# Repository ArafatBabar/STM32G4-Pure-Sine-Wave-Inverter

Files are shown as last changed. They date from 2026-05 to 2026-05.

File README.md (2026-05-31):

# STM32G4-Pure-Sine-Wave-Inverter
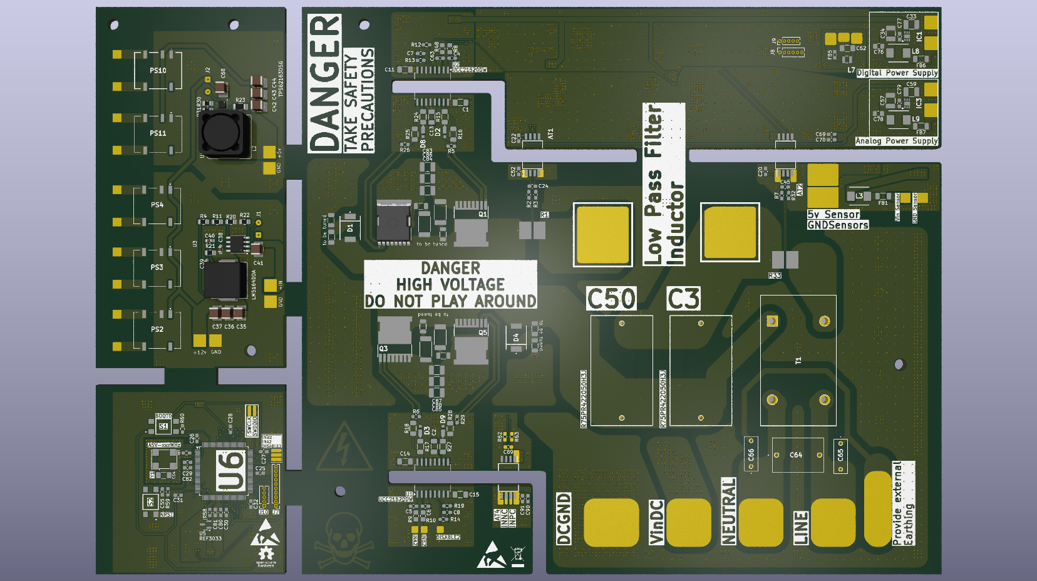
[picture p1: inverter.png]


A 1kW Two-Stage Pure Sine Wave Inverter based on the STM32G474 microcontroller.

The project converts a three-phase AC source into a regulated 400V DC link and then generates a low-distortion 230V RMS 50Hz pure sine wave output using SPWM-controlled full-bridge inverter topology.

## Specifications

| Parameter | Value |
|---|---|
| Output Power | 1kW Peak |
| Continuous Power | 800W |
| Output Voltage | 230V RMS |
| Output Frequency | 50Hz |
| DC Bus Voltage | 400V |
| Switching Frequency | 20kHz |
| Controller | STM32G474QETx |
| Modulation | Unipolar SPWM |
| Output Filter | LC Low Pass |
| Target THD | <3% |

## System Architecture

3 Phase AC
      │
      ▼
Rectifier
      │
      ▼
400V DC Link
      │
      ▼
Full Bridge Inverter
      │
      ▼
LC Filter
      │
      ▼
230V RMS 50Hz Output

## Features

- STM32G474-based control system
- 20kHz SPWM generation
- Isolated gate drivers
- Current sensing
- Voltage sensing
- LC output filtering
- High-voltage DC link architecture
- Modular PCB design
- Future-ready closed-loop control architecture

## Hardware Overview

### Power Stage
- Full bridge MOSFET inverter
- 400V DC bus
- LC output filter

### Controller Board
- STM32G474QETx
- ADC-based sensing
- PWM generation

### Gate Driver Board
- UCC21520 isolated gate driver

### Auxiliary Power Supply
- High-voltage DC/DC converter
- Isolated supplies

## Development Timeline

1. Topology selection
2. Simulation in PSIM
3. Schematic design
4. PCB design
5. Fabrication
6. Assembly
7. Firmware development
8. Hardware validation
9. Final testing

## Team

Project Team:

- Arafat Babar
- Vedant Acharya
- Krisha Pandya
- Ketan Pitroda
- Dev Bhavsar
- Yash Patel
- Raj Gediya
- Pritha Patel

Guides:

- Prof. Ketan Bhavsar
- Prof. Ankit Chauhan

## Design Notes and Lessons Learned

This project was developed as part of an academic power electronics course and represents a significant learning experience for the entire team.

While the system successfully demonstrates the design and implementation of a 1 kW STM32G4-based pure sine wave inverter, the current hardware revision is not without limitations. During development and review, several design decisions were identified that could be improved in future revisions.

Some areas identified for improvement include:

* PCB layout optimization for high-current switching paths.
* Improved isolation and creepage/clearance considerations in certain sections.
* Better placement of decoupling and filtering components.
* Additional protection circuitry and fault handling mechanisms.
* Improved EMI/EMC design practices.
* More comprehensive thermal analysis of power-stage components.
* Further validation of sensing and feedback circuitry under varying operating conditions.

This repository is intentionally published in its current state to document the complete engineering journey, including mistakes, trade-offs, design iterations, and lessons learned.

Engineering progress comes from testing assumptions, identifying weaknesses, and continuously improving designs. Future revisions will incorporate the insights gained from this prototype.

## Known Issues

The current revision contains several areas that will be revisited in future versions:

* Some PCB footprints and placements could be optimized for assembly and serviceability.
* High-current routing can be further improved to reduce loop inductance.
* Additional test points would simplify debugging and validation.
* Certain component selections were driven by availability and academic timelines rather than final production requirements.
* The control firmware is still under active development and tuning.
* The design has not yet undergone long-term reliability testing.

These observations are documented to encourage discussion and to help future iterations of the project.

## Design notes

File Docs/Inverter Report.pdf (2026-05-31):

POWER ELECTRONICS & DRIVES STUDIO | STU 601

## Design and Implementation of a Two-Stage Single-Phase Pure Sine Wave Inverter using STM32G4

This project is submitted as partial fulfillment of the requirement for the Power Electronics and Drives studio for Spring 2025-26.

Electrical and Electronics Engineering Navrachana University

April 2026

POWER ELECTRONICS & DRIVES STUDIO | STU601

### MEMBERS OF GROUP A

Sr. No. | Name | Enrollment ID | Signature
1 | Arafat Babar | 23000159 | __________
2 | Vedant Acharya | 23000229 | __________
3 | Krisha Pandya | 23000386 | __________
4 | Ketan Pitroda | 23000796 | __________
5 | Dev Bhavsar | 23001109 | __________
6 | Yash Patel | 23001111 | __________
7 | Raj Gediya | 23001115 | __________
8 | Pritha Patel | 23001118 | __________

### DECLARATION

We hereby declare that the report entitled “Two-Stage Single-Phase Pure Sine Wave Inverter using STM32G4” is a bonafide record of the work carried out by us in partial fulfillment of the requirements for the completion of the 6th semester Power Electronics and Drives Studio of Bachelor of Technology in Electrical and Electronics Engineering.

We further declare that this work has been carried out by us under the guidance of our supervisor and has not been submitted elsewhere for the completion of any other degree, diploma, or fellowship. All sources of information used in this report have been duly acknowledged.

We also affirm that this project is an original work and has been completed by us to the best of our knowledge and belief.

Signature of the Guide

Name of Guide: ____________________

Designation: ____________________

### ACKNOWLEDGEMENT

We would like to express our sincere gratitude to everyone who supported and guided us throughout the completion of our project titled “Design and Implementation of a Two-Stage Single-Phase Pure Sine Wave Inverter using STM32G4.”

We are highly thankful to Navrachana University for providing us with the opportunity, facilities, and resources required to successfully carry out this project work. The academic environment and technical support offered by the university greatly contributed to the successful completion of this project.

We would like to express our heartfelt gratitude to our respected project guides, Prof. Ketan Bhavsar and Prof. Ankit Chauhan, for their valuable guidance, continuous encouragement, and technical expertise throughout the project. Their insightful suggestions and constant motivation helped us overcome challenges and improve the quality of our work.

We would also like to extend our special thanks to Nicky Joshi and Jitendra Patel for their support, assistance, and helpful guidance during various stages of the project. Their encouragement and technical inputs played an important role in the successful implementation of the system.

This project involved extensive research, circuit design, hardware implementation, programming of the STM32G4 microcontroller, PWM generation, and inverter performance analysis. The teamwork, cooperation, and dedication shown by every group member were instrumental in achieving our objectives successfully.

Finally, we would like to thank all those who directly or indirectly contributed to the completion of this project. Without their support and encouragement, this work would not have been possible.

### ABSTRACT

This project presents the design and implementation of a Two-Stage Single-Phase Pure Sine Wave Inverter using the STM32G4 microcontroller for efficient DC to AC power conversion. The system is designed to generate a stable and low-distortion single-phase AC output suitable for domestic and industrial low-power applications. The inverter employs a two-stage conversion topology consisting of a rectification stage and an inverter stage to achieve improved voltage regulation, waveform quality, and operational reliability.

In the first stage, the AC input supply is converted into DC using an uncontrolled diode bridge rectifier. The rectified output is filtered using a capacitor bank to obtain a stable DC link voltage. In the second stage, a full-bridge inverter topology is implemented using MOSFET switches controlled by the STM32G4 microcontroller. The controller generates Sinusoidal Pulse Width Modulation (SPWM) signals to ensure accurate switching operation and to produce a sinusoidal output waveform with reduced harmonic distortion.

An LC low-pass filter is incorporated at the output stage to eliminate high-frequency switching harmonics and improve the quality of the generated sine wave. The proposed system is capable of delivering a 230 V RMS, 50 Hz single-phase AC output with efficient power conversion and reliable performance. The use of the STM32G4 microcontroller enables precise PWM generation, fast processing capability, flexible control implementation, and enhanced system stability.

The developed inverter system demonstrates advantages such as compact design, reduced Total Harmonic Distortion (THD), improved efficiency, electrical isolation, and scalability for future enhancements. This project highlights the practical implementation of modern power electronic conversion techniques and embedded control systems for pure sine wave inverter applications.

### TABLE OF CONTENTS

### LIST OF CHAPTERS

### LIST OF TABLES

### LIST OF FIGURES

Fig 5.6.1 72V/High Voltage to 12V Converter Schematic Diagram...41

Fig 5.9.1 Microcontroller and Control Interface Schematic Diagram.47

### LIST OF ABBREVIATIONS

Abbreviation | Full Form
AC | Alternating Current
ADC | Analog to Digital Converter
DC | Direct Current
EMI | Electromagnetic Interference
ESR | Equivalent Series Resistance
IC | Integrated Circuit
IoT | Internet of Things
LC Filter | Inductor-Capacitor Filter
MOSFET | Metal Oxide Semiconductor Field Effect Transistor
MCU | Microcontroller Unit
PCB | Printed Circuit Board
PI Controller | Proportional Integral Controller
PSIM | Power Simulation Software
PWM | Pulse Width Modulation
RC Circuit | Resistor Capacitor Circuit
RCD Clamp | Resistor Capacitor Diode Clamp
RMS | Root Mean Square
SPWM | Sinusoidal Pulse Width Modulation

THD | Total Harmonic Distortion
UPS | Uninterruptible Power Supply
VDC | Direct Current Voltage
VAC | Alternating Current Voltage
Hz | Hertz
kHz | Kilohertz
STM32G4 | STMicroelectronics 32-bit Microcontroller Series
GPIO | General Purpose Input Output
ADC | Analog to Digital Converter
ESR | Equivalent Series Resistance
H-Bridge | Full Bridge Inverter Configuration
CPU | Central Processing Unit
USB | Universal Serial Bus

### LIST OF APPENDIX

### CHAPTER 1

### INTRODUCTION

1.1 Background

The increasing demand for reliable and high-quality electrical power has led to the rapid development of power electronic conversion systems. In modern electrical and industrial applications, inverters play a vital role in converting Direct Current (DC) power into Alternating Current (AC) power suitable for domestic, commercial, and industrial loads [1]. Conventional square wave and modified sine wave inverters introduce significant harmonic distortion, reduced efficiency, and poor compatibility with sensitive electronic equipment. Therefore, Pure Sine Wave Inverters have become increasingly important due to their ability to provide clean, stable, and low-distortion AC output similar to utility power systems [2].

A two-stage inverter topology is widely preferred in modern power conversion systems because of its improved voltage regulation, flexibility, efficiency, and control capability [3]. In a two-stage architecture, the first stage performs AC to DC conversion and establishes a stable DC bus, while the second stage converts the DC voltage into a controlled sinusoidal AC output. This approach improves waveform quality, simplifies control implementation, and enhances system stability under varying load conditions [4].

The proposed project focuses on the design and implementation of a Two-Stage Single-Phase Pure Sine Wave Inverter using the STM32G4 microcontroller. The system utilizes a three-phase AC input supply which is fed through a variac for adjustable voltage control. In the first stage, a three-phase full-bridge rectifier converts the AC input into a high-voltage DC output of approximately 400 V DC. The rectified voltage is filtered using a capacitor bank to create a stable DC link for the inverter stage [1].

In the second stage, a full-bridge inverter topology operating at a switching frequency of 20 kHz is implemented using MOSFET switches. The inverter is controlled using Sinusoidal Pulse Width Modulation (SPWM) signals generated by the STM32G4 microcontroller [3]. The high-frequency PWM switching technique allows the inverter to produce an output waveform that closely resembles a pure sine wave. An LC low-pass filter is incorporated at the output stage to eliminate high-frequency harmonics and improve waveform quality [8].

The STM32G4 microcontroller is selected due to its advanced timer peripherals, high-speed processing capability, accurate PWM generation, and efficient real-time control features [5]. The controller also performs voltage and current sensing, PI-based control implementation, fault protection, and system monitoring to ensure safe and reliable operation.

The developed inverter system is designed to generate a stable 230 V, 50 Hz single-phase AC output, making it suitable for residential backup systems, laboratory applications, renewable energy systems, and low-power industrial loads. The project demonstrates the practical implementation of modern embedded control systems and power electronics techniques for efficient energy conversion [2], [4].

1.2 Project Objective

The primary objective of this project is to design and implement a Two-Stage Single-Phase Pure Sine Wave Inverter using the STM32G4 microcontroller capable of producing a stable and low-distortion AC output from a DC source.

The specific objectives of the project are as follows:

1. To design a two-stage power conversion system consisting of a rectification stage and an inverter stage.
2. To convert a three-phase AC supply into a stable high-voltage DC bus using a three-phase full-bridge rectifier and capacitor filtering network [1].
3. To generate a pure sinusoidal AC output of 230 V RMS at 50 Hz using a full-bridge inverter topology.
4. To implement Sinusoidal Pulse Width Modulation (SPWM) techniques using the STM32G4 microcontroller for accurate switching control of MOSFET devices [3], [5].
5. To reduce harmonic distortion in the output waveform using an LC low-pass filter [8].
6. To implement current sensing, voltage sensing, protection mechanisms, and PI control algorithms for improved system reliability and stability.
7. To achieve efficient power conversion with reduced switching losses and improved waveform quality [4].

8. To develop a compact, modular, and scalable inverter system suitable for practical applications and future enhancements.

1.3 Project Scope

The scope of this project includes the complete design, development, testing, and implementation of a two-stage single-phase pure sine wave inverter system using embedded control techniques and power electronic converters.

The project covers the following areas:

1. Design and implementation of the power stage consisting of a three-phase rectifier and full-bridge inverter topology [1].
2. Development of a stable 400 V DC bus using rectification and capacitor filtering techniques.
3. Generation of high-frequency SPWM signals using the STM32G4 microcontroller [5].
4. Design of gate driver circuits for MOSFET switching applications.
5. Implementation of an LC output filter for harmonic reduction and waveform smoothing [8].
6. Integration of voltage and current sensing circuits for feedback and protection.
7. Implementation of PI control algorithms for output regulation and system stability.
8. Testing and analysis of inverter performance under different operating conditions and load variations.
9. Measurement and evaluation of output voltage quality, switching performance, efficiency, and harmonic distortion.

The proposed inverter system can be further extended for applications such as renewable energy integration, solar inverter systems, UPS systems, battery energy storage systems, and industrial motor drive applications [6]. Future improvements may include closed-loop digital control, advanced modulation techniques, higher power ratings, IoT-based monitoring, and improved efficiency optimization methods.

### CHAPTER 2

### LITERATURE REVIEW

2.1 Pure Sine Wave Inverter

An inverter is a power electronic device used to convert Direct Current (DC) into Alternating Current (AC). Inverters are widely used in backup power systems, renewable energy systems, industrial drives, and domestic applications. According to Mohan et al. [1], modern inverter systems mainly focus on improving efficiency, reducing switching losses, and minimizing harmonic distortion in the output waveform.

There are mainly three types of inverter output waveforms: square wave, modified sine wave, and pure sine wave. Among these, pure sine wave inverters provide the best output quality because the generated waveform closely matches the utility AC supply [2]. Pure sine wave inverters are preferred for sensitive electronic devices, medical equipment, communication systems, and industrial loads due to their low Total Harmonic Distortion (THD) and stable operation.

The proposed project implements a pure sine wave inverter using a two-stage conversion system. The first stage converts AC input into DC using a rectifier circuit, while the second stage converts the DC link voltage into sinusoidal AC output using SPWM switching techniques.

2.2 Two-Stage Inverter Topology

The two-stage inverter topology is widely used in modern power conversion systems because of its improved flexibility, voltage regulation capability, and waveform quality [4]. In this topology, the first stage consists of an AC-DC converter or rectifier that generates a stable DC bus voltage. The second stage consists of a DC-AC inverter that produces the required AC output waveform.

In the proposed system, a three-phase full-bridge rectifier is used to convert the three-phase AC supply into approximately 400 V DC. A capacitor bank is connected across the DC link to reduce voltage ripple and maintain a stable DC bus voltage. The inverter stage uses a full-bridge MOSFET configuration operating at high switching frequency to generate AC output voltage.

The two-stage structure provides better isolation between rectification and inversion processes, improves output stability, and allows independent control of both stages. This topology is commonly used in UPS systems, renewable energy systems, and high-performance inverter applications [1], [4].

2.3 Sinusoidal Pulse Width Modulation (SPWM)

Pulse Width Modulation (PWM) is one of the most important switching techniques used in inverter systems. PWM techniques are used to control switching devices and generate output voltages with reduced harmonic distortion [3]. Among different PWM techniques, Sinusoidal Pulse Width Modulation (SPWM) is widely used because of its simple implementation and high-quality output waveform generation.

Holmes and Lipo [3] explained that SPWM is generated by comparing a high-frequency triangular carrier signal with a sinusoidal reference signal. The comparison produces PWM pulses that control the switching of MOSFETs in the inverter circuit. By varying the modulation index and switching frequency, the output voltage magnitude and waveform quality can be controlled.

SPWM significantly reduces lower-order harmonics and improves inverter efficiency. High-frequency switching also reduces the size of output filters required for harmonic reduction [8]. In this project, the STM32G4 microcontroller generates 20 kHz SPWM signals to control the inverter switching operation.

2.4 STM32G4 Microcontroller

Microcontrollers play an important role in modern inverter systems due to their ability to provide accurate switching control, sensing, protection, and feedback implementation. The STM32G4 series microcontroller developed by STMicroelectronics [5] is specifically designed for power electronic and motor control applications.

The STM32G4 controller provides advanced timer peripherals, high-speed Analog-to-Digital Converters (ADC), PWM generation units, dead-time insertion capability, and fault handling mechanisms. These features make the controller highly suitable for inverter applications requiring high-frequency switching and real-time control.

In the proposed project, the STM32G4 microcontroller is used for SPWM pulse generation, current and voltage sensing, PI control implementation, and protection handling. The controller ensures precise switching operation and stable output waveform generation.

2.5 MOSFET Switching Devices

Power semiconductor devices are the key components in inverter systems. MOSFETs are widely used in high-frequency inverter applications because of their fast switching speed, low switching losses, and simple gate drive requirements [2].

According to Ahmed [9], MOSFET-based inverter systems provide improved switching performance and higher efficiency in medium-power applications. MOSFETs are voltage-controlled devices and require comparatively lower gate drive power than conventional bipolar transistors.

In the proposed project, MOSFETs are used in a full-bridge inverter configuration for high-frequency switching operation. The switching signals generated by the STM32G4 controller control the MOSFET operation to generate SPWM output pulses.

2.6 LC Output Filter

The output waveform of an inverter contains high-frequency switching harmonics generated due to PWM operation. Therefore, filters are required to reduce harmonic content and improve waveform quality. LC low-pass filters are commonly used in pure sine wave inverter systems because of their ability to attenuate high-frequency harmonics while allowing the fundamental frequency component to pass [8].

Ang and Oliva [10] explained that proper filter design is important for achieving stable output voltage and minimizing distortion. The inductance and capacitance values must be selected carefully based on switching frequency, load conditions, and output voltage requirements.

In this project, an LC filter is connected at the inverter output stage to smooth the SPWM waveform and generate a clean 230 V, 50 Hz sinusoidal AC output.

2.7 Control and Protection System

Modern inverter systems require efficient control and protection mechanisms to ensure safe and reliable operation. Feedback control techniques such as PI controllers are widely used for maintaining stable output voltage under varying load conditions [6].

Krishnan [6] explained that voltage sensing and current sensing circuits are necessary for monitoring system performance and implementing closed-loop control. Protection systems are also required to prevent damage caused by overcurrent, short circuits, overheating, and abnormal operating conditions.

The proposed inverter system incorporates voltage sensing, current sensing, PI control algorithms, and fault handling techniques using the STM32G4 microcontroller. These features improve system stability, reliability, and operational safety.

2.8 Summary of Literature Review

Based on the literature survey, it is observed that modern pure sine wave inverter systems require efficient PWM techniques, high-frequency switching devices, advanced digital controllers, and effective filtering methods for achieving high-quality AC power conversion. Most researchers focused on improving inverter efficiency, reducing harmonic distortion, and implementing reliable embedded control systems.

The concepts studied from the reviewed literature were used in the development of the proposed project, which implements a two-stage pure sine wave inverter using a three-phase rectifier, STM32G4-based SPWM control, MOSFET switching, and LC filtering techniques.

### CHAPTER 3

### SYSTEM DESIGN APPROACH

3.1 Design Objective

The primary objective of the proposed system is to design and implement a Two-Stage Single-Phase Pure Sine Wave Inverter using the STM32G4 microcontroller capable of generating a stable and low-distortion AC output suitable for practical electrical applications. The system is designed to convert a three-phase AC input into a regulated DC voltage and further convert the DC voltage into a single-phase sinusoidal AC output using high-frequency switching techniques [1], [4].

The design aims to achieve efficient power conversion, reduced harmonic distortion, stable voltage regulation, and reliable switching operation. Another major objective is to implement Sinusoidal Pulse Width Modulation (SPWM) using the STM32G4 microcontroller for accurate control of MOSFET switching devices [3], [5]. The proposed system also focuses on implementing voltage sensing, current sensing, output filtering, and protection mechanisms to improve overall system stability and reliability [4], [6].

The inverter is designed to provide a 230 V RMS, 50 Hz pure sine wave output with improved waveform quality and reduced Total Harmonic Distortion (THD) [1], [2], [8].

3.2 Selection of Two-Stage Topology

The two-stage inverter topology was selected because of its improved flexibility, better voltage regulation capability, modular structure, and enhanced waveform quality compared to conventional single-stage inverter systems [4]. In a two-stage architecture, the power conversion process is divided into two separate stages: the rectification stage and the inversion stage.

In the first stage, a three-phase full-bridge rectifier converts the AC input supply into a high-voltage DC output. The rectified voltage is filtered using a capacitor bank to create a stable DC bus voltage. In the second stage, the DC voltage is converted into single-phase AC output using a full-bridge inverter operating with high-frequency SPWM switching [1], [3].

The two-stage topology provides several advantages such as improved output voltage stability, better harmonic reduction capability, independent control of rectifier and inverter stages, easier implementation of digital control techniques, improved scalability and modularity, and better suitability for high-frequency switching applications [4], [6]. Due to these advantages, the two-stage topology is widely used in UPS systems, renewable energy systems, and modern pure sine wave inverter applications [1], [2].

3.3 Block Diagram and System Flow

The overall system consists of three major sections: the power stage, inverter stage, and control stage. The system begins with a three-phase AC supply connected through a variac for adjustable input voltage control. The AC input is fed to a three-phase full-bridge rectifier which converts the AC voltage into approximately 400 V DC.

The rectified DC output is filtered using a capacitor bank to reduce voltage ripple and establish a stable DC link voltage. This DC bus is then supplied to the inverter stage consisting of a full-bridge MOSFET configuration operating with SPWM switching at 20 kHz.

The STM32G4 microcontroller generates SPWM pulses required for MOSFET switching control. The inverter output is passed through an LC low-pass filter to eliminate switching harmonics and generate a clean sinusoidal AC waveform. Voltage sensing and current sensing circuits continuously monitor the system parameters and provide feedback to the controller for stable operation and protection handling.

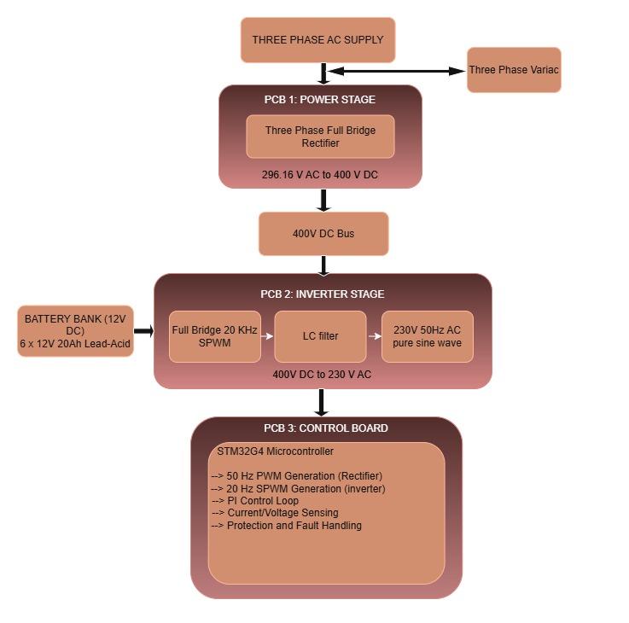
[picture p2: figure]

Fig 3.3.1 System Flow Chart
3.4 DC Link Design Concept

The DC link stage plays an important role in maintaining stable inverter operation and reducing voltage ripple between the rectifier and inverter stages. The DC link consists of a capacitor bank connected across the rectifier output to store energy and smooth the pulsating DC voltage generated by the rectifier [1], [4].

The capacitor bank helps in reducing ripple voltage, stabilizing DC bus voltage, improving inverter performance, providing temporary energy storage during switching operation, and reducing voltage fluctuations caused by load variations. Proper DC link design is essential for maintaining stable inverter operation and improving overall power conversion efficiency [2], [6].

The DC bus voltage for the proposed system is designed around 400 V DC. Proper capacitor selection is important because insufficient capacitance may increase ripple voltage and affect inverter output quality. High-voltage electrolytic capacitors with suitable ripple current ratings are used to ensure stable operation [1], [4].

The DC link design also improves transient response and ensures continuous power delivery to the inverter stage during high-frequency switching operation [3], [8].

3.5 Switching Strategy Selection (SPWM)

Sinusoidal Pulse Width Modulation (SPWM) was selected as the switching strategy for the proposed inverter system because of its simplicity, effectiveness, and ability to generate high-quality sinusoidal output waveforms with reduced harmonic distortion [3].

In SPWM, a high-frequency triangular carrier signal is compared with a low-frequency sinusoidal reference signal. The comparison generates PWM pulses that control the switching operation of the MOSFETs in the full-bridge inverter circuit. By varying the modulation index and switching frequency, the output voltage magnitude and waveform quality can be controlled [3], [8].

The major advantages of SPWM include reduced Total Harmonic Distortion (THD), better output voltage control, improved waveform quality, reduced filter size requirements, higher inverter efficiency, and simple implementation using digital controllers [2], [3].

The STM32G4 microcontroller generates 20 kHz SPWM signals with proper dead-time insertion to avoid shoot-through conditions in the inverter switches. The modulation index and switching frequency are selected carefully to achieve stable output voltage and efficient switching performance [5], [8].

3.6 Output Filtering Approach

The inverter output produced by SPWM switching contains high-frequency harmonics due to rapid switching operation of the MOSFETs. Therefore, an output filter is required to eliminate switching harmonics and obtain a smooth sinusoidal waveform [3], [8].

An LC low-pass filter is used in the proposed system because of its effective harmonic attenuation capability and simple design structure. The inductor opposes sudden current changes while the capacitor smooths voltage fluctuations, resulting in a cleaner output waveform [8], [10].

The LC filter is designed based on switching frequency, output frequency, load conditions, harmonic attenuation requirements, and voltage and current ratings.

Proper filter parameter selection is important for maintaining waveform quality and reducing Total Harmonic Distortion (THD) [3], [10].

The filter significantly reduces high-frequency switching components and improves the quality of the generated 230 V, 50 Hz AC output waveform [2], [8].

3.7 Design Specifications

The major design specifications of the proposed inverter system are listed below:

Table No 3.7.1 Key Design Parameters

Parameter | Value
Input Supply | Three-Phase AC Supply
DC Bus Voltage | Approximately 400 V DC
Output Voltage | 230V RMS
Output Frequency | 50 Hz
Inverter Type | Full-Bridge Single-Phase Inverter
Switching Technique | SPWM
Switching Frequency | 20 kHz
Controller | STM32G4 Microcontroller
Output Filter | LC Low-Pass Filter
Switching Devices | MOSFETs
Protection Features | Overcurrent, Overvoltage, Fault Handling
Output Waveform | Pure Sine Wave

3.8 Design Methodology Overview

The design methodology of the proposed inverter system follows a systematic approach involving circuit design, controller implementation, simulation, hardware development, testing, and performance evaluation [1], [4].

Initially, the overall system architecture and inverter topology were selected based on output requirements and power conversion efficiency. The rectifier stage and DC link section were designed to generate a stable high-voltage DC bus. The inverter stage was then designed using a full-bridge MOSFET configuration for high-frequency switching operation [1], [2].

The STM32G4 microcontroller was programmed to generate SPWM signals for inverter control. Voltage and current sensing circuits were integrated for monitoring and protection purposes. The LC filter parameters were selected to minimize harmonic distortion and improve waveform quality [3], [5], [8].

After hardware implementation, the system performance was tested under different operating conditions and load variations. Output voltage, waveform quality, switching performance, and inverter stability were analyzed to verify proper system operation [4], [6].

The proposed methodology provides a modular and scalable inverter design suitable for future improvements and practical power electronic applications [2], [4].

### CHAPTER 4

### PSIM SIMULATION

4.1 Introduction to Simulation

To validate the proposed system design before hardware implementation, simulations were carried out using PSIM software. Simulation helps in analyzing system behavior, verifying circuit operation, and evaluating output waveform quality under ideal conditions.

The simulation was performed in two stages. First, a single-phase inverter was simulated to understand SPWM-based DC-to-AC conversion. Then, the complete system including the three-phase rectifier, DC link, inverter, and LC filter was simulated to analyze overall performance.

4.2 SPWM Controlled Inverter Simulation

4.2.1 Circuit Description

The simulated circuit represents a single-phase full-bridge inverter using MOSFET switches. A DC input of approximately 400V is applied to the inverter.

SPWM is used as the switching technique, where a sinusoidal reference signal (50 Hz) is compared with a high-frequency triangular carrier signal (20 kHz). The resulting PWM signals control the switching of the MOSFETs in the H-bridge configuration.

The MOSFETs operate in diagonal pairs to produce alternating polarity across the load, resulting in a PWM-based AC waveform.

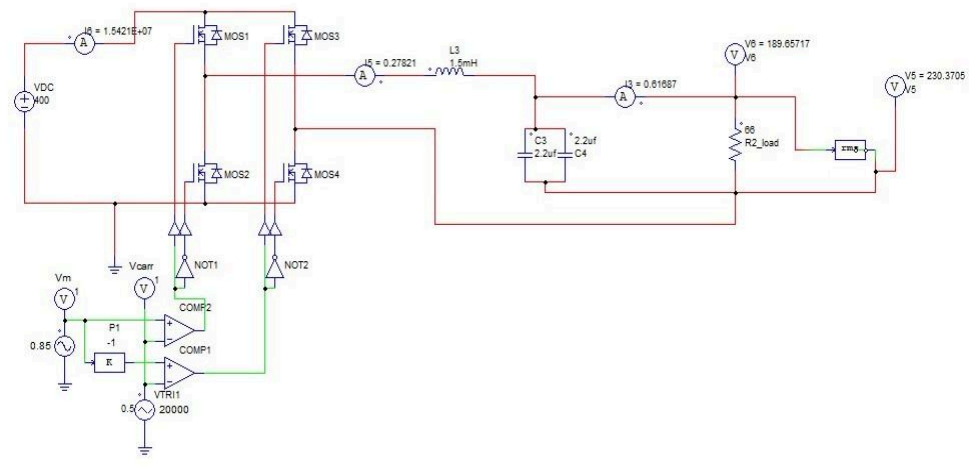
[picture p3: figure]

Fig 4.2.1 Inverter Simulation Circuit

4.2.2 Output Filtering

The output of the inverter consists of high-frequency PWM pulses, which contain harmonic components. To obtain a smooth sinusoidal waveform, an LC low-pass filter is used.

The inductor reduces rapid changes in current, while the capacitor smooths voltage variations. This combination effectively removes high-frequency components and retains the fundamental frequency.

4.3 Complete System Simulation (Rectifier + Inverter)

4.3.1 Rectifier Stage

The first stage of the simulation consists of a three-phase uncontrolled diode bridge rectifier. It converts the three-phase AC input into pulsating DC.

A capacitor bank is connected at the output of the rectifier to smooth the pulsating DC and form a DC link. This DC link provides a stable input voltage to the inverter stage.

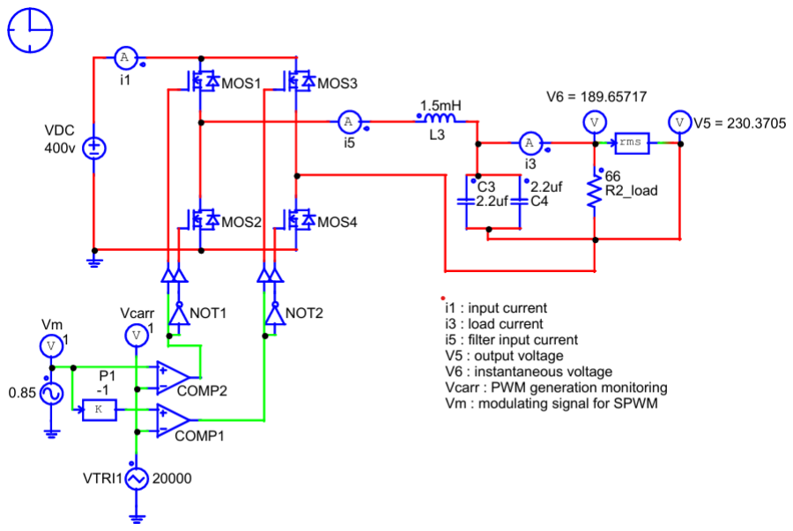
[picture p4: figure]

Fig 4.3.1 Rectifier Simulation Circuit

4.3.2 Inverter Stage

The DC link voltage is fed into the full-bridge inverter. The inverter uses SPWM signals to generate a high-frequency PWM waveform, which approximates a sinusoidal output.

The switching frequency is maintained at 20 kHz to ensure effective filtering and reduced harmonic distortion.

4.3.3 Output Filtering and Load

An LC filter is connected at the output of the inverter to remove high-frequency switching harmonics. The filtered output is applied to a resistive load.

The output waveform obtained after filtering closely resembles a sinusoidal waveform with reduced distortion.

4.4 Simulation Results and Analysis

4.4.1 Load Current

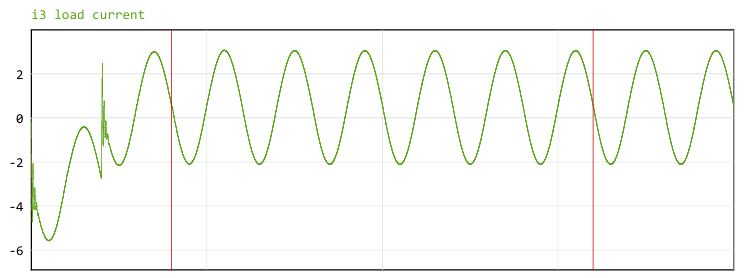
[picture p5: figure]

Fig 4.4.1 Load Current Waveform

The load current waveform shows a smooth sinusoidal pattern after filtering. This indicates that the LC filter effectively removes high-frequency components and allows only the fundamental frequency to pass.

4.4.2 Filter Input Current

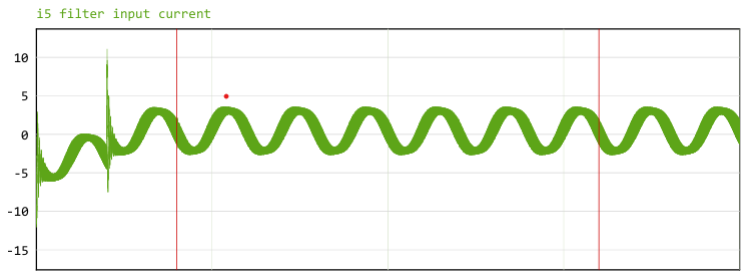
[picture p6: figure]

Fig 4.4.2 Filter Input Current Waveform

The current entering the filter contains high-frequency components due to switching action in the inverter. This waveform appears more distorted compared to the load current, confirming that the filter is actively removing unwanted harmonics.

4.4.3 Output Voltage

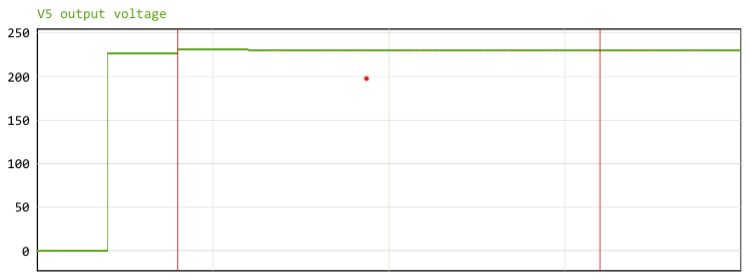
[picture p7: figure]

Fig 4.4.3 Output Voltage Waveform

The output voltage waveform after the LC filter is observed to be a stable sinusoidal waveform with an RMS value close to 230V. This confirms that the inverter is capable of producing the required output voltage.

4.4.4 Instantaneous Voltage

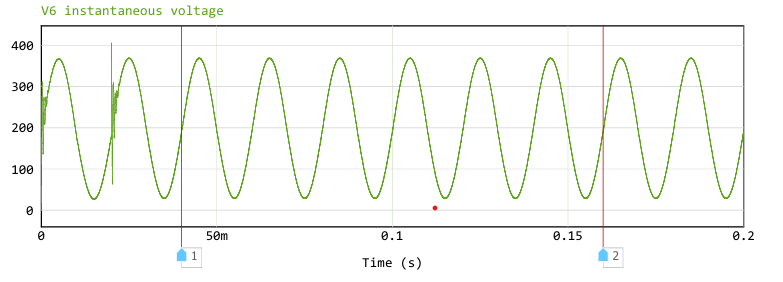
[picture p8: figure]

Fig 4.4.4 Instantaneous Voltage Waveform

The instantaneous voltage waveform shows the variation of voltage over time before filtering. It contains high-frequency switching components along with the fundamental frequency. After filtering, these high-frequency components are removed, resulting in a clean sinusoidal waveform.

4.5 Summary of Simulation

The simulation results confirm the proper operation of the two-stage inverter system. The rectifier successfully converts AC input into DC, and the inverter generates an AC output using SPWM control. The LC filter effectively reduces harmonic distortion and produces a clean sinusoidal waveform.

The simulation validates the design approach and provides confidence for proceeding to hardware implementation.

### CHAPTER 5

### HARDWARE IMPLEMENTATION

5.1 Introduction

After validating the system through simulation, the proposed two-stage inverter system was implemented in hardware. The implementation involves the design and integration of multiple subsystems, including the rectifier stage, DC link, inverter stage, gate driver circuits, auxiliary power supplies, sensing circuits, filtering stages, and control unit.

The hardware is designed using a modular approach, where power and control circuits are separated to improve safety, reduce noise interference, and simplify debugging. Proper consideration is given to isolation, thermal performance, and PCB layout to ensure reliable operation at high power levels.
5.2 Rectifier Circuit Design

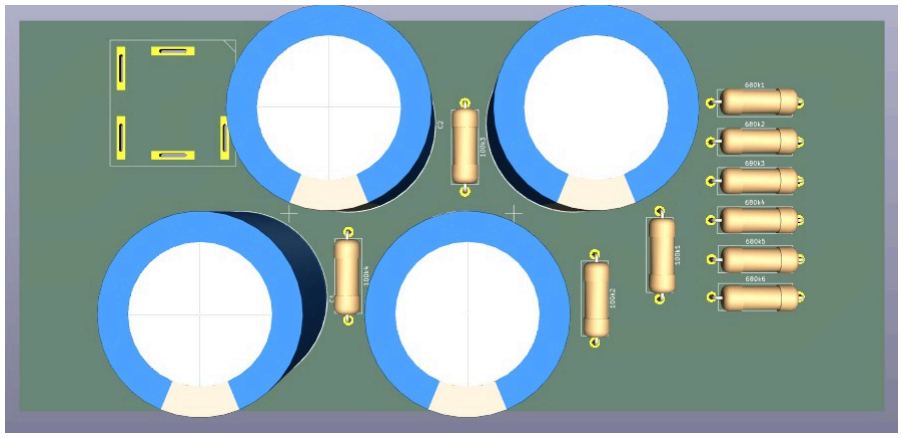
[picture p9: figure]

Fig 5.2.1 Rectifier PCB -1

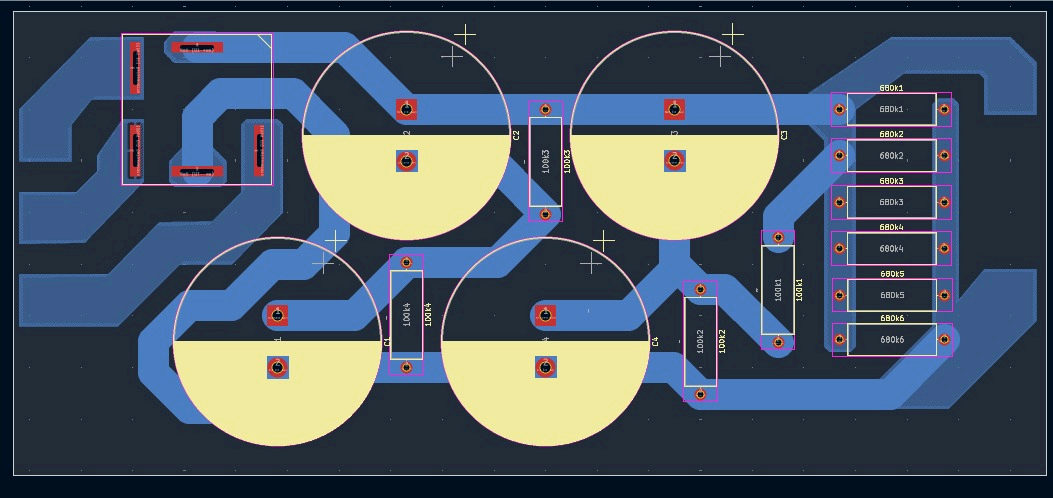
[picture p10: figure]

Fig 5.2.2 Rectifier PCB -2

Description:

The rectifier stage consists of a three-phase uncontrolled diode bridge, which converts the AC input supply into pulsating DC. The bridge is formed using six power diodes arranged in a full-wave configuration, where each phase contributes to the output during different intervals of the AC cycle.

Working Principle:

During operation, at any instant, two diodes conduct, one from the positive group and one from the negative group, allowing current to flow from the highest positive phase to the most negative phase. This results in a pulsating DC output with reduced ripple compared to single-phase rectification.

Key Components:

1. Power Diodes (D1–D6): Handle high voltage and current
2. Input Terminals: Three-phase AC supply
3. Output Terminals: DC output to DC link

Importance in System:

This stage provides the required DC voltage for the inverter. Its simplicity, reliability, and ruggedness make it suitable for high-power applications.

5.3 DC Link Design

Description:

The DC link connects the rectifier stage to the inverter and acts as an intermediate energy storage element. It consists of a capacitor bank designed to smooth the pulsating DC output from the rectifier.

Working Principle:

The capacitors charge during voltage peaks and discharge during voltage dips, thereby reducing ripple and maintaining a nearly constant DC voltage. This stabilized voltage is critical for proper inverter operation.

Design Considerations:

1. High voltage rating (≈400V)
2. High ripple current handling
3. Low Equivalent Series Resistance (ESR)
4. Proper spacing and PCB layout

Importance in System:

A stable DC link ensures consistent inverter performance, reduces stress on switching devices, and improves output waveform quality.

5.4 Inverter Circuit Design

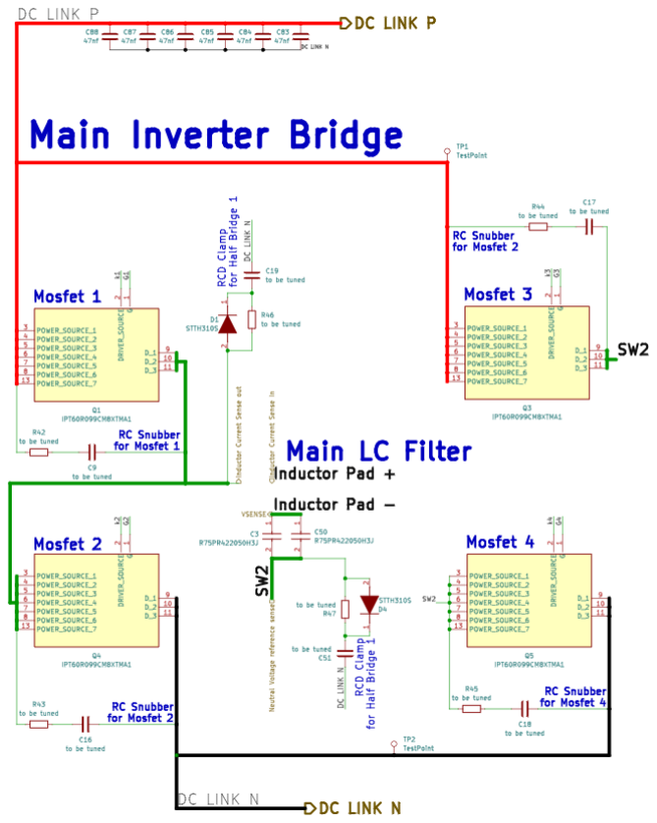
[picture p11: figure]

Fig 5.4.1 Inverter Schematic Diagram

Description:

The inverter stage converts DC into AC using a full-bridge configuration consisting of four N-channel MOSFETs. The MOSFETs are controlled using SPWM signals generated by the microcontroller.

Working Principle:

The MOSFETs operate in diagonal pairs (Q1–Q4 and Q2–Q3). By switching these pairs alternately, the polarity of the voltage across the load is reversed, producing an AC waveform. The switching is performed at a high frequency (20 kHz) to enable efficient filtering.

Protection Features:

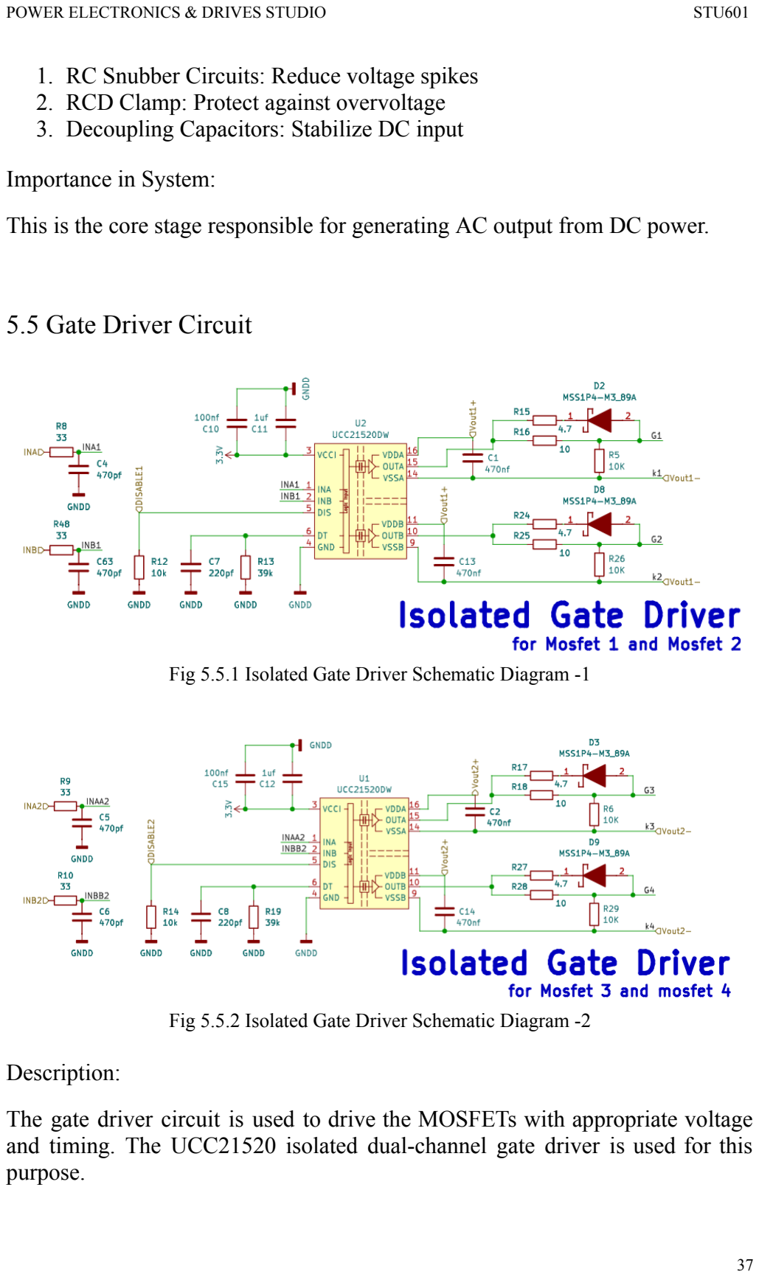
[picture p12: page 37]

1. RC Snubber Circuits: Reduce voltage spikes
2. RCD Clamp: Protect against overvoltage
3. Decoupling Capacitors: Stabilize DC input

Importance in System:

This is the core stage responsible for generating AC output from DC power.

5.5 Gate Driver Circuit

Fig 5.5.1 Isolated Gate Driver Schematic Diagram -1

Fig 5.5.2 Isolated Gate Driver Schematic Diagram -2

Description:

The gate driver circuit is used to drive the MOSFETs with appropriate voltage and timing. The UCC21520 isolated dual-channel gate driver is used for this purpose.

Working Principle:

The driver receives PWM signals from the microcontroller and amplifies them to drive the MOSFET gates. It also provides electrical isolation between the control and power stages.

Key Features:

1. Reinforced isolation
2. Dead-time control to prevent shoot-through
3. High switching speed
4. Separate isolated supplies

Importance in System:

Ensures safe, efficient, and synchronized switching of MOSFETs.

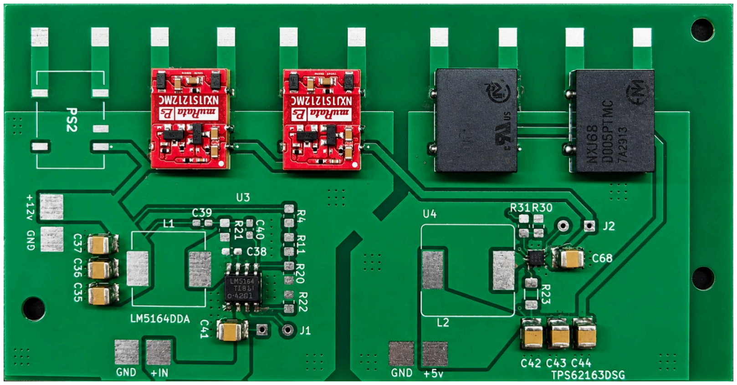
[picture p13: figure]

Fig 5.5.3 Isolated Gate Driver PCB

5.6 Auxiliary Power Supply Design

5.6.1 72V/High Voltage to 12V Converter

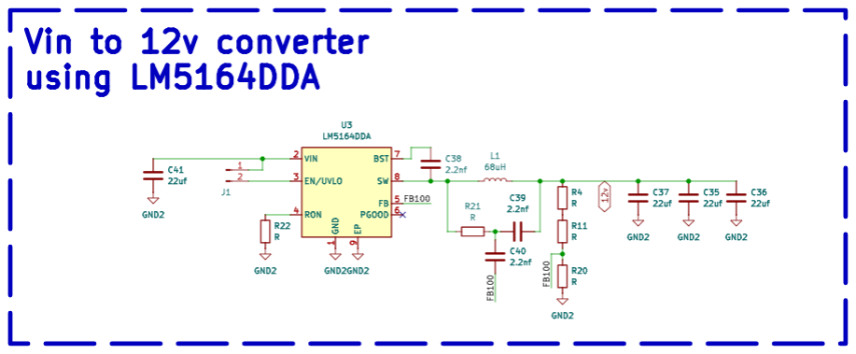
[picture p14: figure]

Fig 5.6.1 72V/High Voltage to 12V Converter Schematic Diagram

This converter steps down the high input voltage to 12V, which is used to power gate drivers and intermediate circuits.

5.6.2 12V to 5V Converter

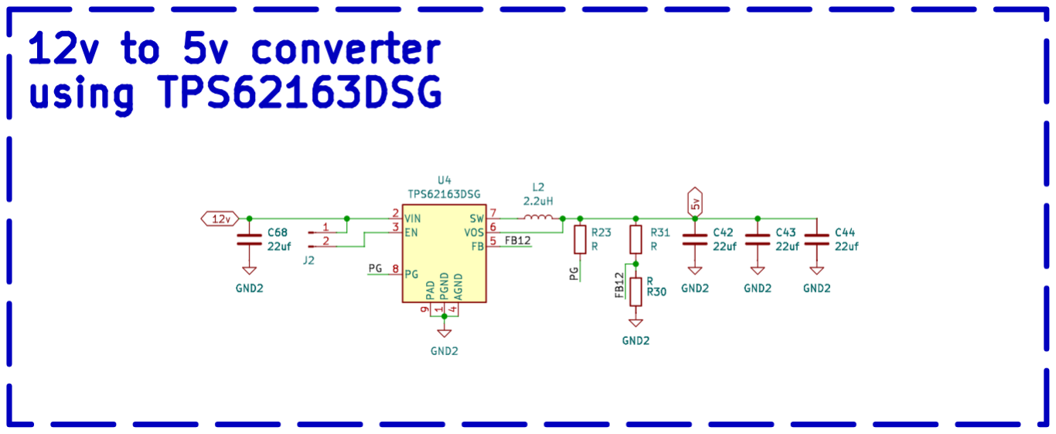
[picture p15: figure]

Fig 5.6.2 12V to 5V Converter Schematic Diagram The 12V to 5V buck converter provides a stable 5V supply for low-voltage components such as sensors and auxiliary circuits.

5.6.3 Isolated Power Supply

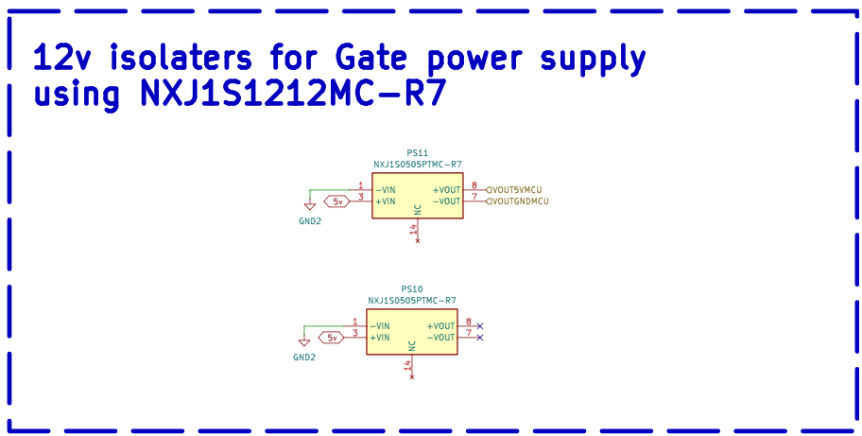
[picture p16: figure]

Fig 5.6.3 Isolated Power Supply Schematic Diagram -1

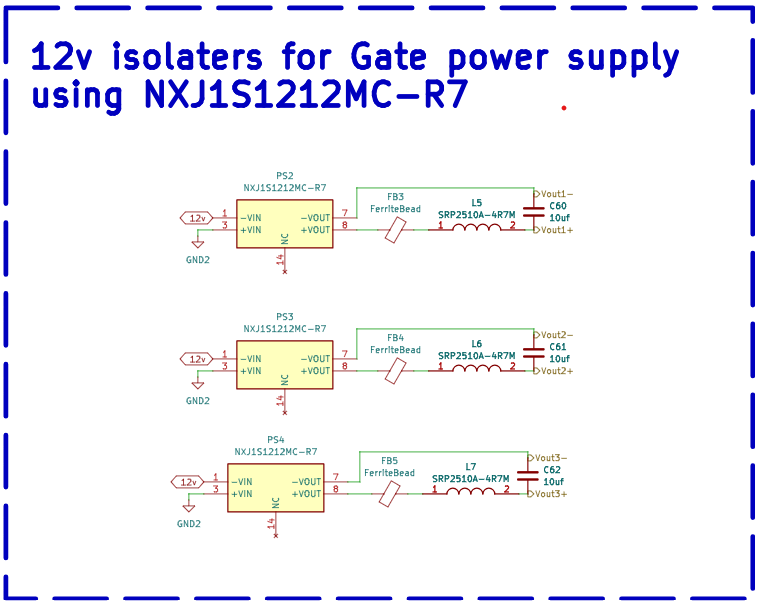
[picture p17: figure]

Fig 5.6.4 Isolated Power Supply Schematic Diagram -2 Isolated DC-DC converters are used to provide an isolated ±12V supply for gate drivers. This ensures safe operation and prevents noise coupling between control and power circuits.

5.7 Sensing and Measurement Circuits

5.7.1 Output Current Measurement

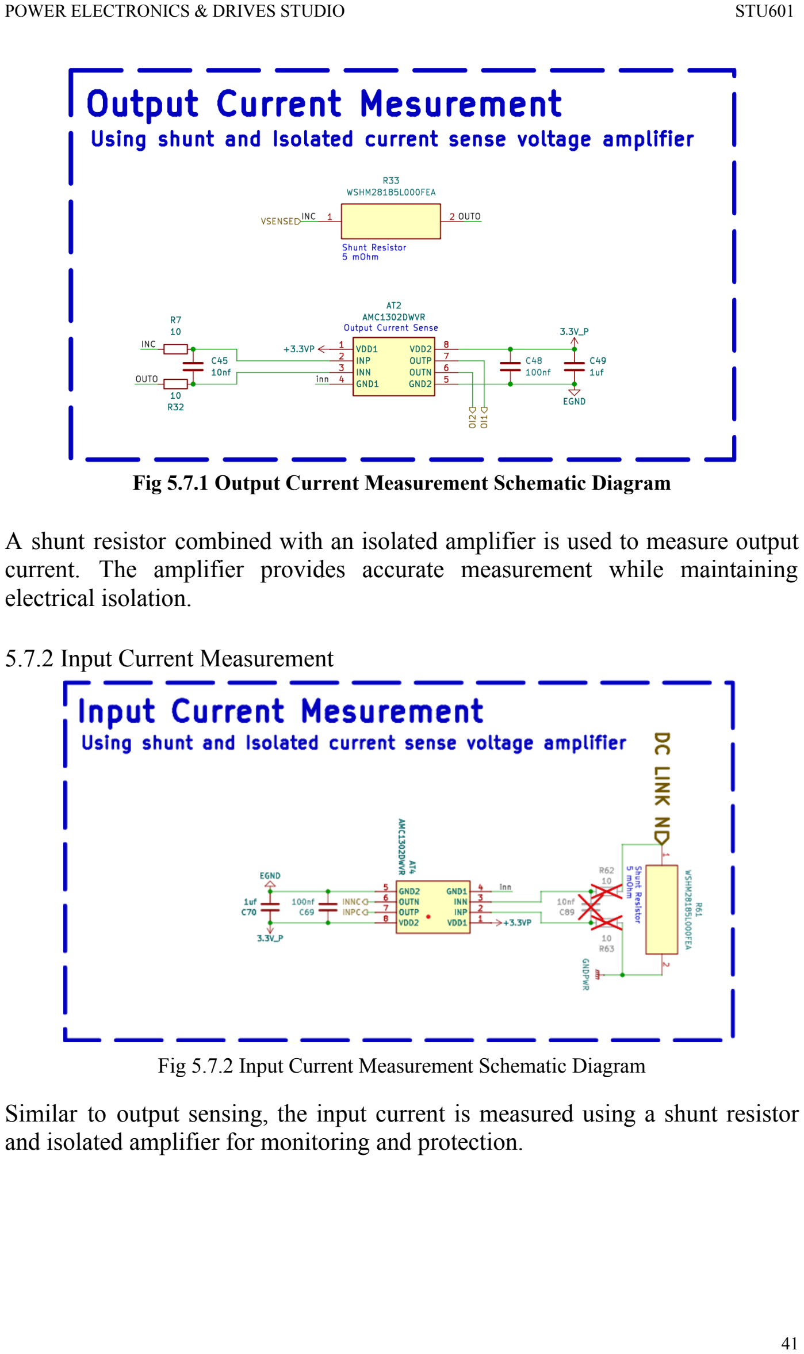
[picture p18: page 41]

Fig 5.7.1 Output Current Measurement Schematic Diagram

A shunt resistor combined with an isolated amplifier is used to measure output current. The amplifier provides accurate measurement while maintaining electrical isolation.

5.7.2 Input Current Measurement

Fig 5.7.2 Input Current Measurement Schematic Diagram Similar to output sensing, the input current is measured using a shunt resistor and isolated amplifier for monitoring and protection.

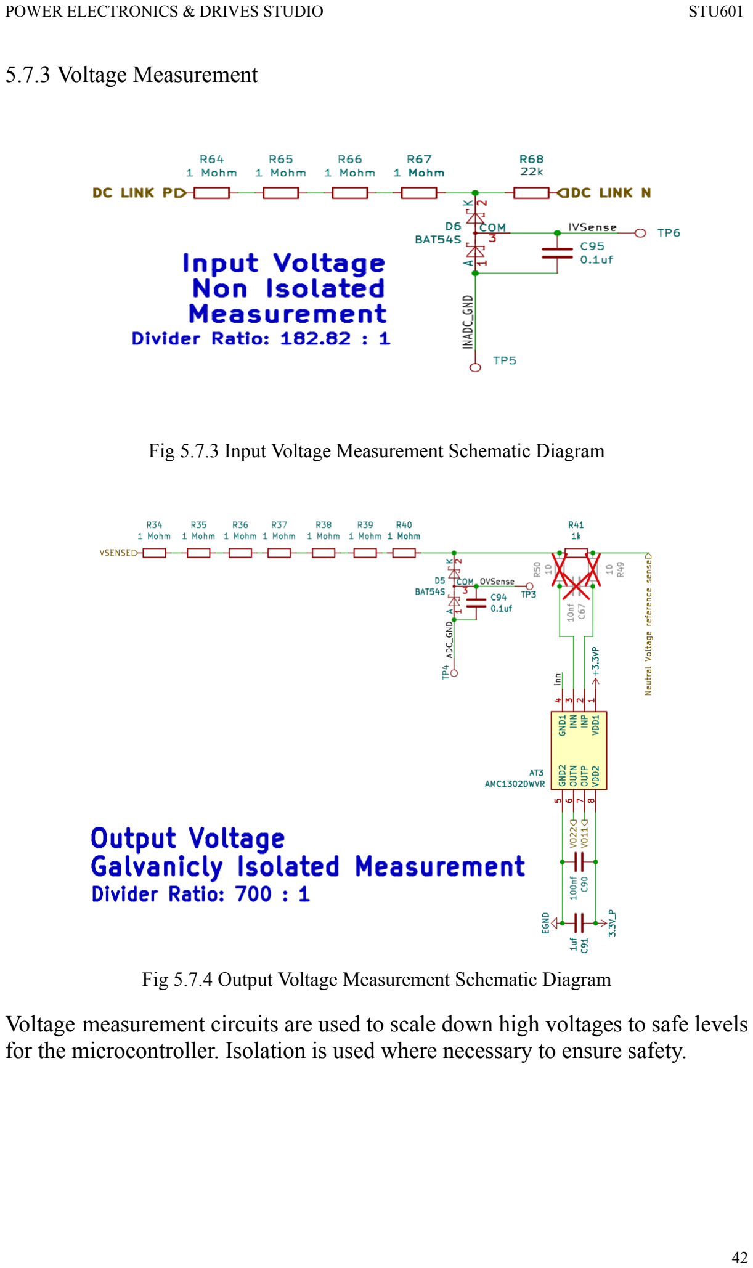
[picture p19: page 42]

5.7.3 Voltage Measurement

Fig 5.7.3 Input Voltage Measurement Schematic Diagram

Fig 5.7.4 Output Voltage Measurement Schematic Diagram Voltage measurement circuits are used to scale down high voltages to safe levels for the microcontroller. Isolation is used where necessary to ensure safety.

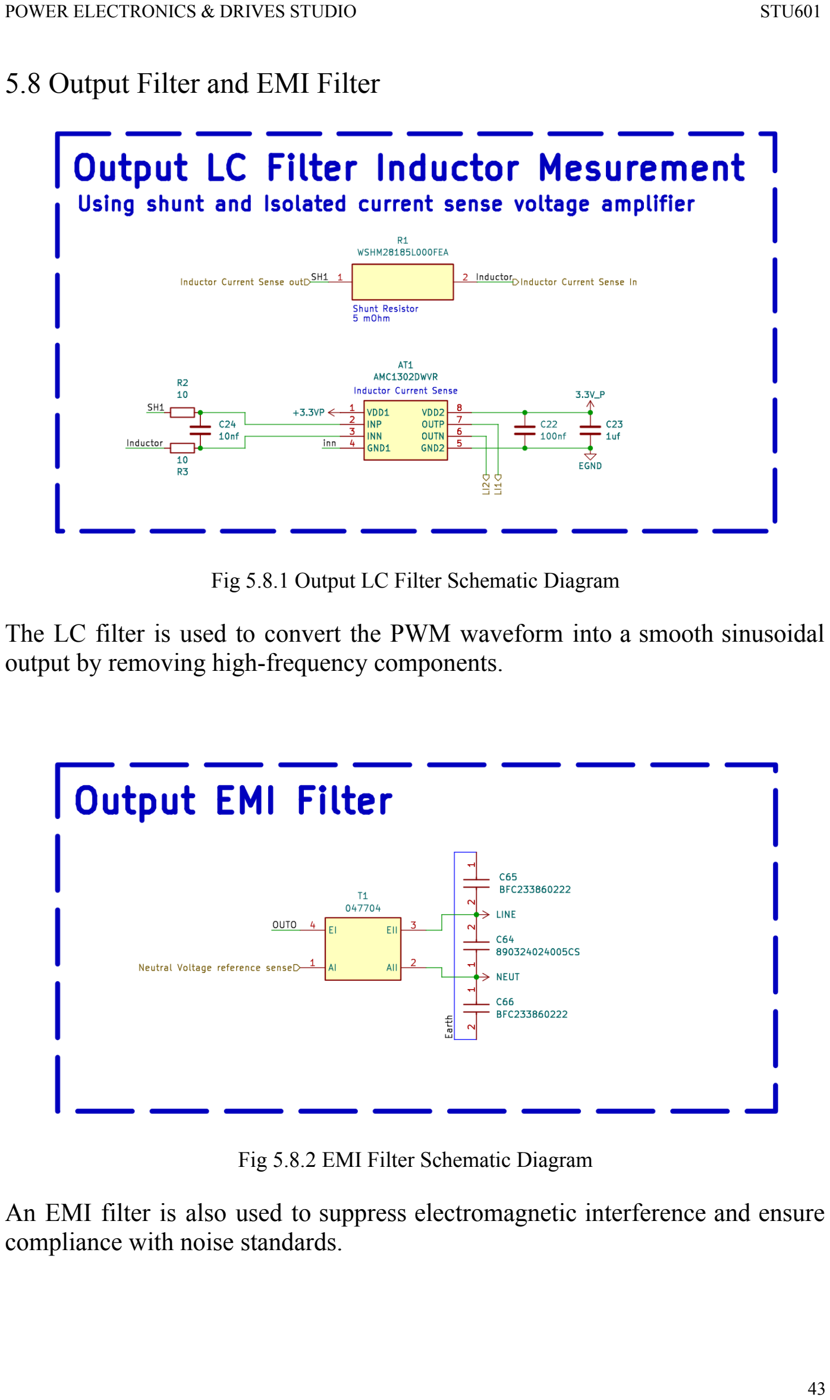
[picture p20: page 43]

5.8 Output Filter and EMI Filter

Fig 5.8.1 Output LC Filter Schematic Diagram

The LC filter is used to convert the PWM waveform into a smooth sinusoidal output by removing high-frequency components.

Fig 5.8.2 EMI Filter Schematic Diagram

An EMI filter is also used to suppress electromagnetic interference and ensure compliance with noise standards.

5.9 Microcontroller and Control Interface

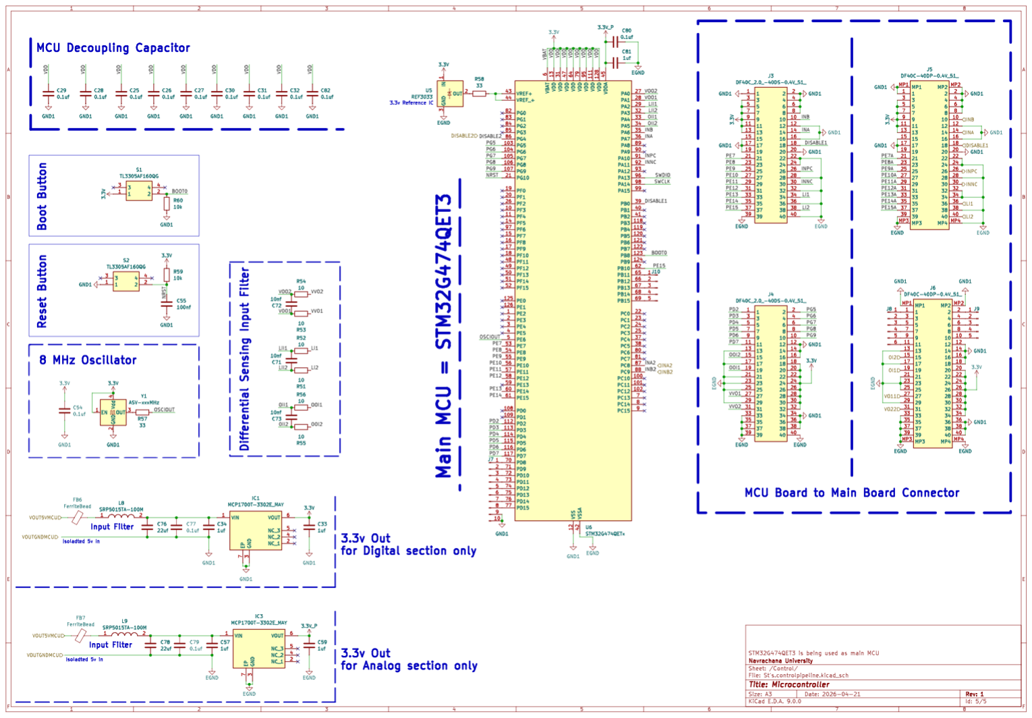
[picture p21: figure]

Fig 5.9.1 Microcontroller and Control Interface Schematic Diagram

The above schematic represents the microcontroller and control interface of the inverter system. The STM32G474QET3 microcontroller acts as the central control unit, responsible for generating SPWM signals, processing feedback signals, and controlling the switching of the inverter.

The circuit includes supporting components such as decoupling capacitors, clock oscillator, reset circuitry, input filtering, voltage regulation, and connector interfaces to ensure stable and reliable operation.

5.9.1 STM32G4 Microcontroller
The STM32G4 microcontroller is the main processing unit of the system. It generates high-frequency PWM signals based on SPWM logic and controls the inverter switching through gate drivers.
It also receives feedback signals such as output voltage and current, enabling closed-loop control and system protection.
5.9.2 Decoupling Capacitor Network

Multiple decoupling capacitors are connected across the power supply pins of the microcontroller. These capacitors filter high-frequency noise and stabilize the supply voltage.
Smaller capacitors handle high-frequency noise, while larger capacitors provide bulk energy storage. This ensures reliable operation and prevents unwanted fluctuations during switching.
5.9.3 Clock Circuit (8 MHz Oscillator)
An external 8 MHz crystal oscillator is used to provide an accurate clock signal to the microcontroller.
This clock is essential for precise timing of PWM signals and overall system synchronization. Stable clock operation directly affects switching accuracy and output waveform quality.
5.9.4 Reset Circuit
The reset circuit ensures that the microcontroller starts in a known state during power-up or fault conditions.
A push-button reset allows manual restarting of the system, while the resistor-capacitor network ensures proper reset timing.
5.9.5 Boot Configuration Circuit
The boot configuration circuit determines the startup mode of the microcontroller. It ensures that the program is executed from internal memory during normal operation.
5.9.6 Input Signal Conditioning (Filtering Section)
Input signals from sensing circuits pass through filtering networks before reaching the microcontroller.
These filters remove noise and ensure that only clean signals are processed. This improves measurement accuracy and prevents incorrect control decisions due to noise.
5.9.7 Voltage Regulation (3.3V Supply)
The microcontroller operates at 3.3V, which is derived from regulated power supply circuits.
Separate regulation is provided for digital and analog sections to reduce noise interference. This improves ADC accuracy and overall system performance.

5.9.8 MCU to Main Board Connector Interface

The connector interface links the microcontroller board with the main power board.
It carries:
1. PWM signals → gate drivers
2. Feedback signals → MCU
3. Power supply lines
This modular design allows easy debugging, replacement, and system scalability.

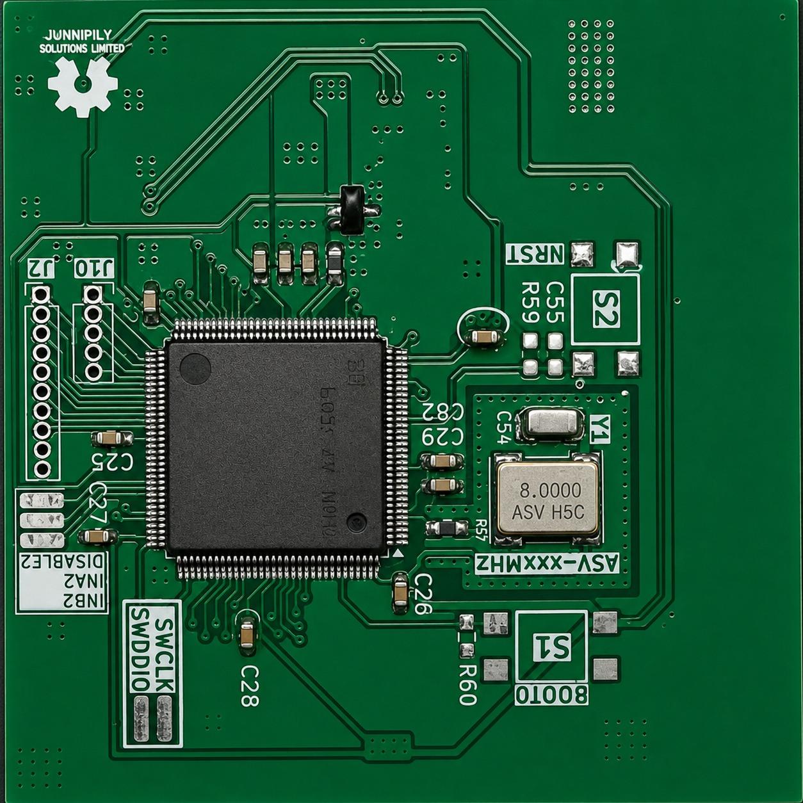
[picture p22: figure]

Fig 5.9.2 MCU PCB
5.10 PCB Design and Implementation

The system is implemented using a modular PCB design to separate power and control circuits. Proper grounding, isolation, and routing techniques are used to minimize noise and improve performance.

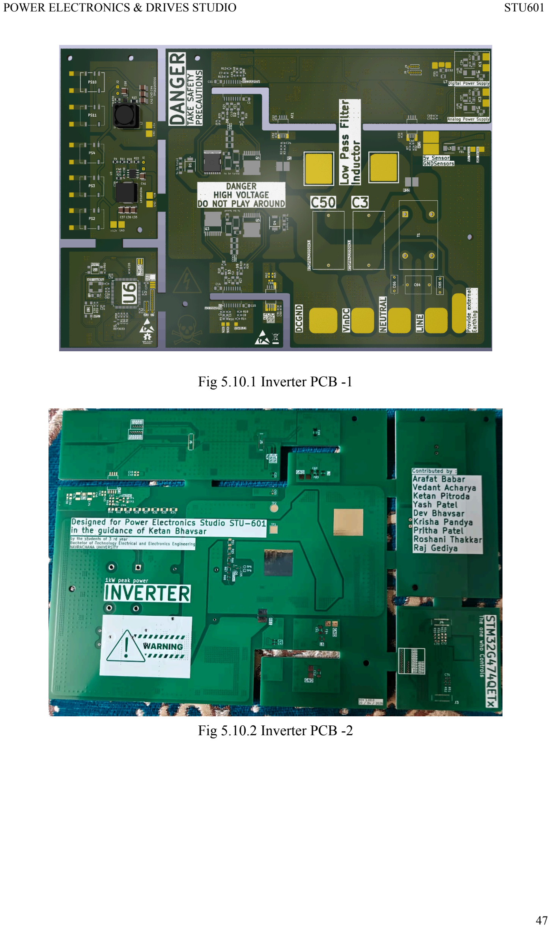
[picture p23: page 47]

Fig 5.10.1 Inverter PCB -1

Fig 5.10.2 Inverter PCB -2

5.11 Summary of Components

Component | Part Number | Rating | Purpose | Used In
Power MOSFET | IPT60R099CM8XT MA1 | 600V, 30A | Main switching device for the inverter, handles high voltage DC bus | Full-Bridg e Inverter
Power MOSFET | IPT034N15NM6AT MA1 | 150V, 194A | High current switching is used in lower voltage stages or auxiliary circuits | Switching Stage
Current Sense Resistor | WSHM28185L000F EB | 5 mΩ, 7W, 1% | Measures current for monitoring and protection | Protection Circuit
Oscillator | ASV-8.000MHZ-EJ-T | 8 MHz | Provides a clock signal for the microcontroller | Control Circuit
DC-DC Converter (Isolated) | NXJ1S0505PTMC-R 7 | 5V, 0.2A | Provides an isolated power supply for the control/gate driver | Control & Driver Circuit
Buck Converter | TPS62163DSGT | High frequency (2.25 MHz), step-down regulator | Converts higher DC voltage to lower required levels | Power Supply Stage
LDO Regulator | MCP1700-3302E | 3.3V, 250mA | Provides a stable voltage for the microcontroller | Control Circuit
Microcontroll er | STM32G4 | High-speed MCU with PWM support | Generates SPWM signals and controls inverter operation | Control Unit
Rectifier | Diode Bridge (3-phase) | ≥400V, suitable current rating | Converts AC input to DC | Rectifier Stage

DC Link Capacitor | Electrolytic Capacitor | ~400V rating, high capacitance | Smoothens DC output and reduces ripple | DC Link
Gate Driver | Gate Driver IC (isolated/non-isolated ) | Suitable gate voltage (10–15V) | Drives MOSFET gates for switching | Driver Circuit
Output Filter | LC Filter | Designed for 50 Hz output | Removes harmonics and smoothens waveform | Output Stage
Load | Resistive Load | As per testing (e.g., 1kW) | Testing and performance evaluation | Output

Table No 5.11.1 Summary of Components

### CHAPTER 6

### RESULT AND ANALYSIS

Experimental Test Bench Description:

1. Three-Phase Uncontrolled Rectifier Module: Converts the Single-phase AC input into a pulsating DC output. The module is housed in a transparent acrylic enclosure and feeds the DC bus voltage to the inverter stage.
2. High-Frequency Variable Inverter PCB: The primary hardware prototype implementing the full-bridge MOSFET inverter topology with SPWM control. The board integrates the gate driver circuits (UCC21520), LC output filter, snubber protection, and auxiliary power supply sub-circuits.
3. Auxiliary (AV) Power Supply Module: Provides regulated low-voltage DC supply for the control circuitry, gate drivers, and sensing subsystems.
4. STM32G4 Microcontroller Control Board: Generates 20 kHz SPWM switching signals and manages voltage/current sensing, PI control, dead-time insertion, and fault protection.
5. Tektronix TBS1022 DSO (Scientech): Two-channel digital storage oscilloscope used for real-time waveform acquisition and measurement of switching and output signals.
6. Laptop Workstation: Runs the embedded programming and real-time monitoring interface for the STM32G4 controller via USB/SWD programming port.

Two-Stage Single-Phase Pure Sine Wave Inverter System

Oscilloscope Configuration and Measurement Setup

Parameter | Channel 1 (CH1) | Channel 2 (CH2)
Signal Observed | SPWM Gate Drive Signal | Output Voltage Response
Coupling Mode | DC | DC
Vertical Scale (V/div) | 1.00 V | 100 mV
Bandwidth Limit | OFF (Full 25 MHz) | OFF (Full 25 MHz)
Probe Attenuation | 1X Voltage | 1X Voltage
Invert Function | OFF | OFF
Time Base (ms/div) | 5.00 ms | 5.00 ms
Total Acquisition Window | 50 ms (10 divisions) | 50 ms (10 divisions)
Trigger Position (M Pos) | 3.600 ms | 3.600 ms
CH2 DC Level Reading | — | −33.9 mV
Acquisition Status | Stop (Frozen waveform) | Stop (Frozen waveform)
Date / Time Stamp | 22-May-2026 14:07 | 22-May-2026 14:07

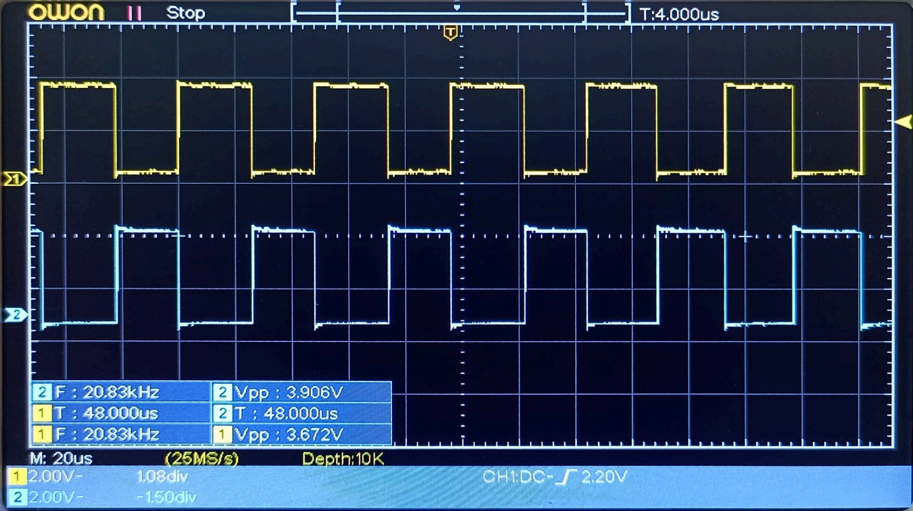
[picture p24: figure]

Tektronix TBS1022 DSO connected to inverter PCB output terminals

The time base of 5.00 ms/div provides a total acquisition window of 50 ms across the ten horizontal divisions of the display. This window spans exactly one full period of the 50 Hz fundamental output frequency, allowing simultaneous observation of both the high-frequency switching waveform (20 kHz SPWM) and the complete 50 Hz output cycle. DC coupling was employed on both channels to ensure that any DC offset components present in the circuit are accurately represented without signal suppression.

### APPENDIX

Appendix A – Block Diagram of Proposed System
This appendix contains the overall block diagram of the proposed Two-Stage Single-Phase Pure Sine Wave Inverter using STM32G4. The block diagram illustrates the complete power flow and control architecture of the system including:
1. Three-phase AC input supply
2. Three-phase rectifier stage
3. DC link capacitor bank
4. Full-bridge inverter stage
5. STM32G4 control board
6. SPWM generation
7. LC output filter
8. Voltage and current sensing circuits
The block diagram is used to understand the interconnection between various stages of the inverter system and the overall system operation.

Appendix B – PSIM Simulation Circuits

This appendix includes the PSIM simulation models developed for validating the inverter design before hardware implementation. The following simulation circuits are included:

1. SPWM controlled full-bridge inverter
2. Three-phase rectifier circuit
3. Complete two-stage inverter simulation
4. LC filter implementation

The simulations were used to analyze switching performance, waveform quality, harmonic reduction, and inverter output characteristics.

Appendix C – Output Waveforms

This appendix contains the waveform results obtained during simulation and testing. The included waveforms are:

1. Load current waveform
2. Filter input current waveform
3. Output voltage waveform
4. Instantaneous voltage waveform
5. SPWM switching pulses

The waveform analysis confirms the successful generation of a pure sine wave output with reduced harmonic distortion.
Appendix D – PCB Layouts and Hardware

This appendix contains the PCB layouts and hardware design files used in the implementation of the inverter system. The following hardware sections are included:

1. Rectifier PCB
2. Inverter PCB
3. Gate driver PCB
4. STM32G4 control board PCB
5. Auxiliary power supply PCB

The appendix also includes hardware photographs and assembled system images for reference.

Appendix E – Schematic Diagrams

This appendix contains detailed schematic diagrams of all major subsystems used in the project, including:

1. Full-bridge inverter schematic
2. Gate driver circuit schematic
3. Voltage sensing circuits
4. Current sensing circuits
5. DC-DC converter circuits

6. LC filter schematic
7. EMI filter schematic
8. STM32G4 control interface schematic

These schematics provide complete circuit-level understanding of the implemented inverter system.

Appendix F – Component Datasheets

This appendix contains datasheets of important electronic components used in the project for design reference and specification verification. The major datasheets included are:

1. STM32G4 Microcontroller
2. UCC21520 Gate Driver IC
3. Power MOSFETs
4. DC-DC Converter Modules
5. Current Sense Amplifiers
6. Voltage Regulators
7. Electrolytic Capacitors

The datasheets were referred to during circuit design, component selection, and hardware implementation.
Appendix G – Source Code and PWM Configuration

This appendix contains the embedded C source code developed for the STM32G4 microcontroller. The source code includes:

1. SPWM generation logic
2. Timer configuration
3. ADC configuration
4. Voltage and current sensing routines
5. Protection algorithms
6. PWM dead-time insertion
7. Interrupt handling routines

The appendix also contains details of PWM frequency selection, modulation index configuration, and control logic implementation.

Appendix H – Testing and Safety Precautions

This appendix describes the testing procedures and safety precautions followed during hardware implementation and experimentation. The following precautions were considered:

1. Proper electrical isolation
2. Safe grounding techniques
3. High-voltage handling precautions
4. Use of insulated probes and equipment
5. Controlled startup using variac
6. Thermal monitoring of switching devices

These precautions ensured safe operation during inverter testing and performance evaluation.

Appendix I - Groups of members

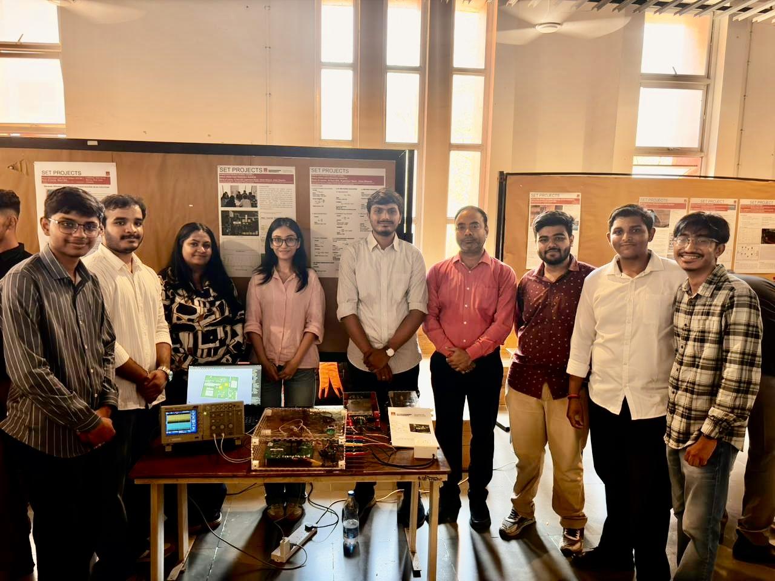
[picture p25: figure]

Group A: Project Team, Power Electronics & Drives Studio (STU 601)

“The team successfully designed and implemented a modular two-stage pure sine wave inverter system capable of generating a stable 230 V RMS, 50 Hz single-phase AC output. The project encompassed a three-phase full-bridge rectifier stage, a 400 V DC bus design, a full-bridge MOSFET inverter controlled via 20 kHz SPWM signals, LC output filtering, isolated gate driver circuits, and PI-based closed-loop control - all implemented on custom-designed PCBs and verified through PSIM simulation and hardware testing using a Tektronix TBS1022 DSO.”

### REFERENCE

[1] N. Mohan, T. M. Undeland, and W. P. Robbins, Power Electronics: Converters, Applications, and Design, 3rd ed. Hoboken, NJ, USA: John Wiley & Sons, 2003.
[2] M. H. Rashid, Power Electronics: Circuits, Devices, and Applications, 4th ed. Noida, India: Pearson Education, 2014.
[3] D. G. Holmes and T. A. Lipo, Pulse Width Modulation for Power Converters: Principles and Practice. Hoboken, NJ, USA: Wiley-IEEE Press, 2003.
[4] B. K. Bose, Modern Power Electronics and AC Drives. Upper Saddle River, NJ, USA: Prentice Hall PTR, 2002.
[5] STMicroelectronics, “STM32G4 Series Advanced Arm®-based 32-bit MCUs,” STMicroelectronics, Geneva, Switzerland, 2023.
[6] R. Krishnan, Electric Motor Drives: Modeling, Analysis, and Control. Upper Saddle River, NJ, USA: Prentice Hall, 2001.
[7] H. Patel and V. Agarwal, “MATLAB-Based Modeling to Study the Effects of SPWM Techniques on Voltage Source Inverter,” International Journal of Power Electronics, vol. 2, no. 3, pp. 1–8, 2018.
[8] J. Holtz, “Pulsewidth Modulation for Electronic Power Conversion,” Proceedings of the IEEE, vol. 82, no. 8, pp. 1194–1214, Aug. 1994.
[9] A. Ahmed, Power Electronics for Technology. New Delhi, India: Pearson Education, 1999.
[10] S. Ang and A. Oliva, Power-Switching Converters, 3rd ed. Boca Raton, FL, USA: CRC Press, 2010.

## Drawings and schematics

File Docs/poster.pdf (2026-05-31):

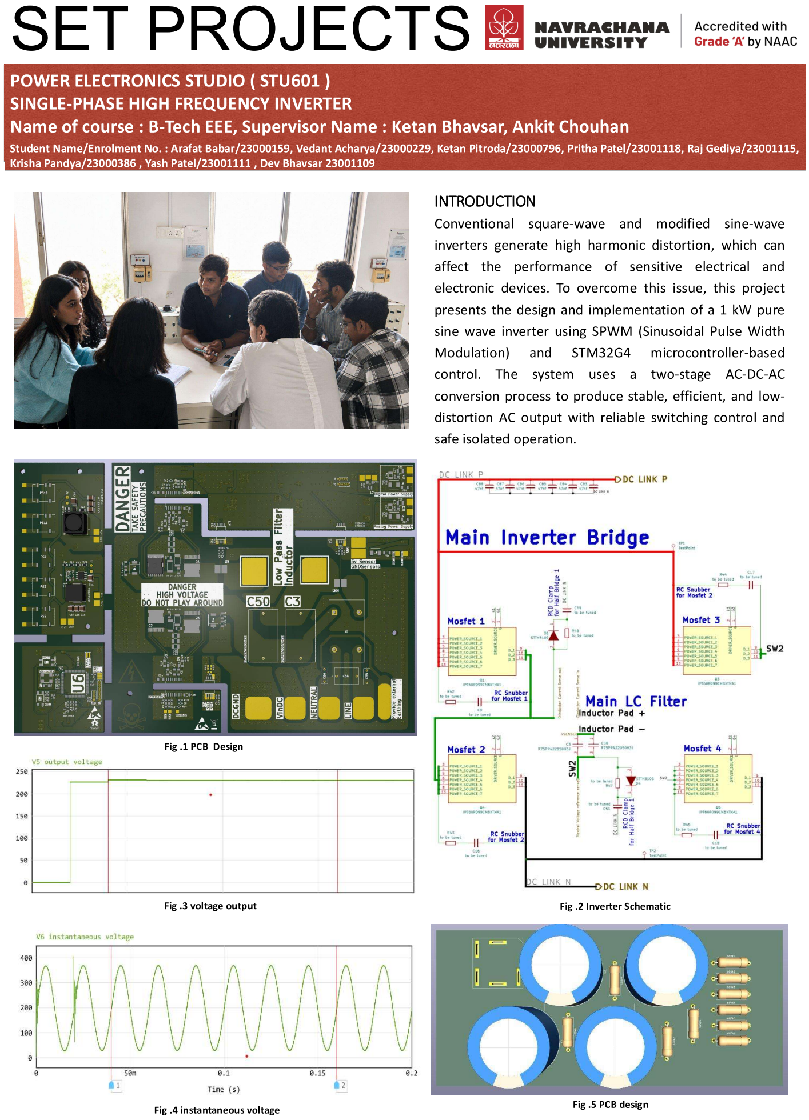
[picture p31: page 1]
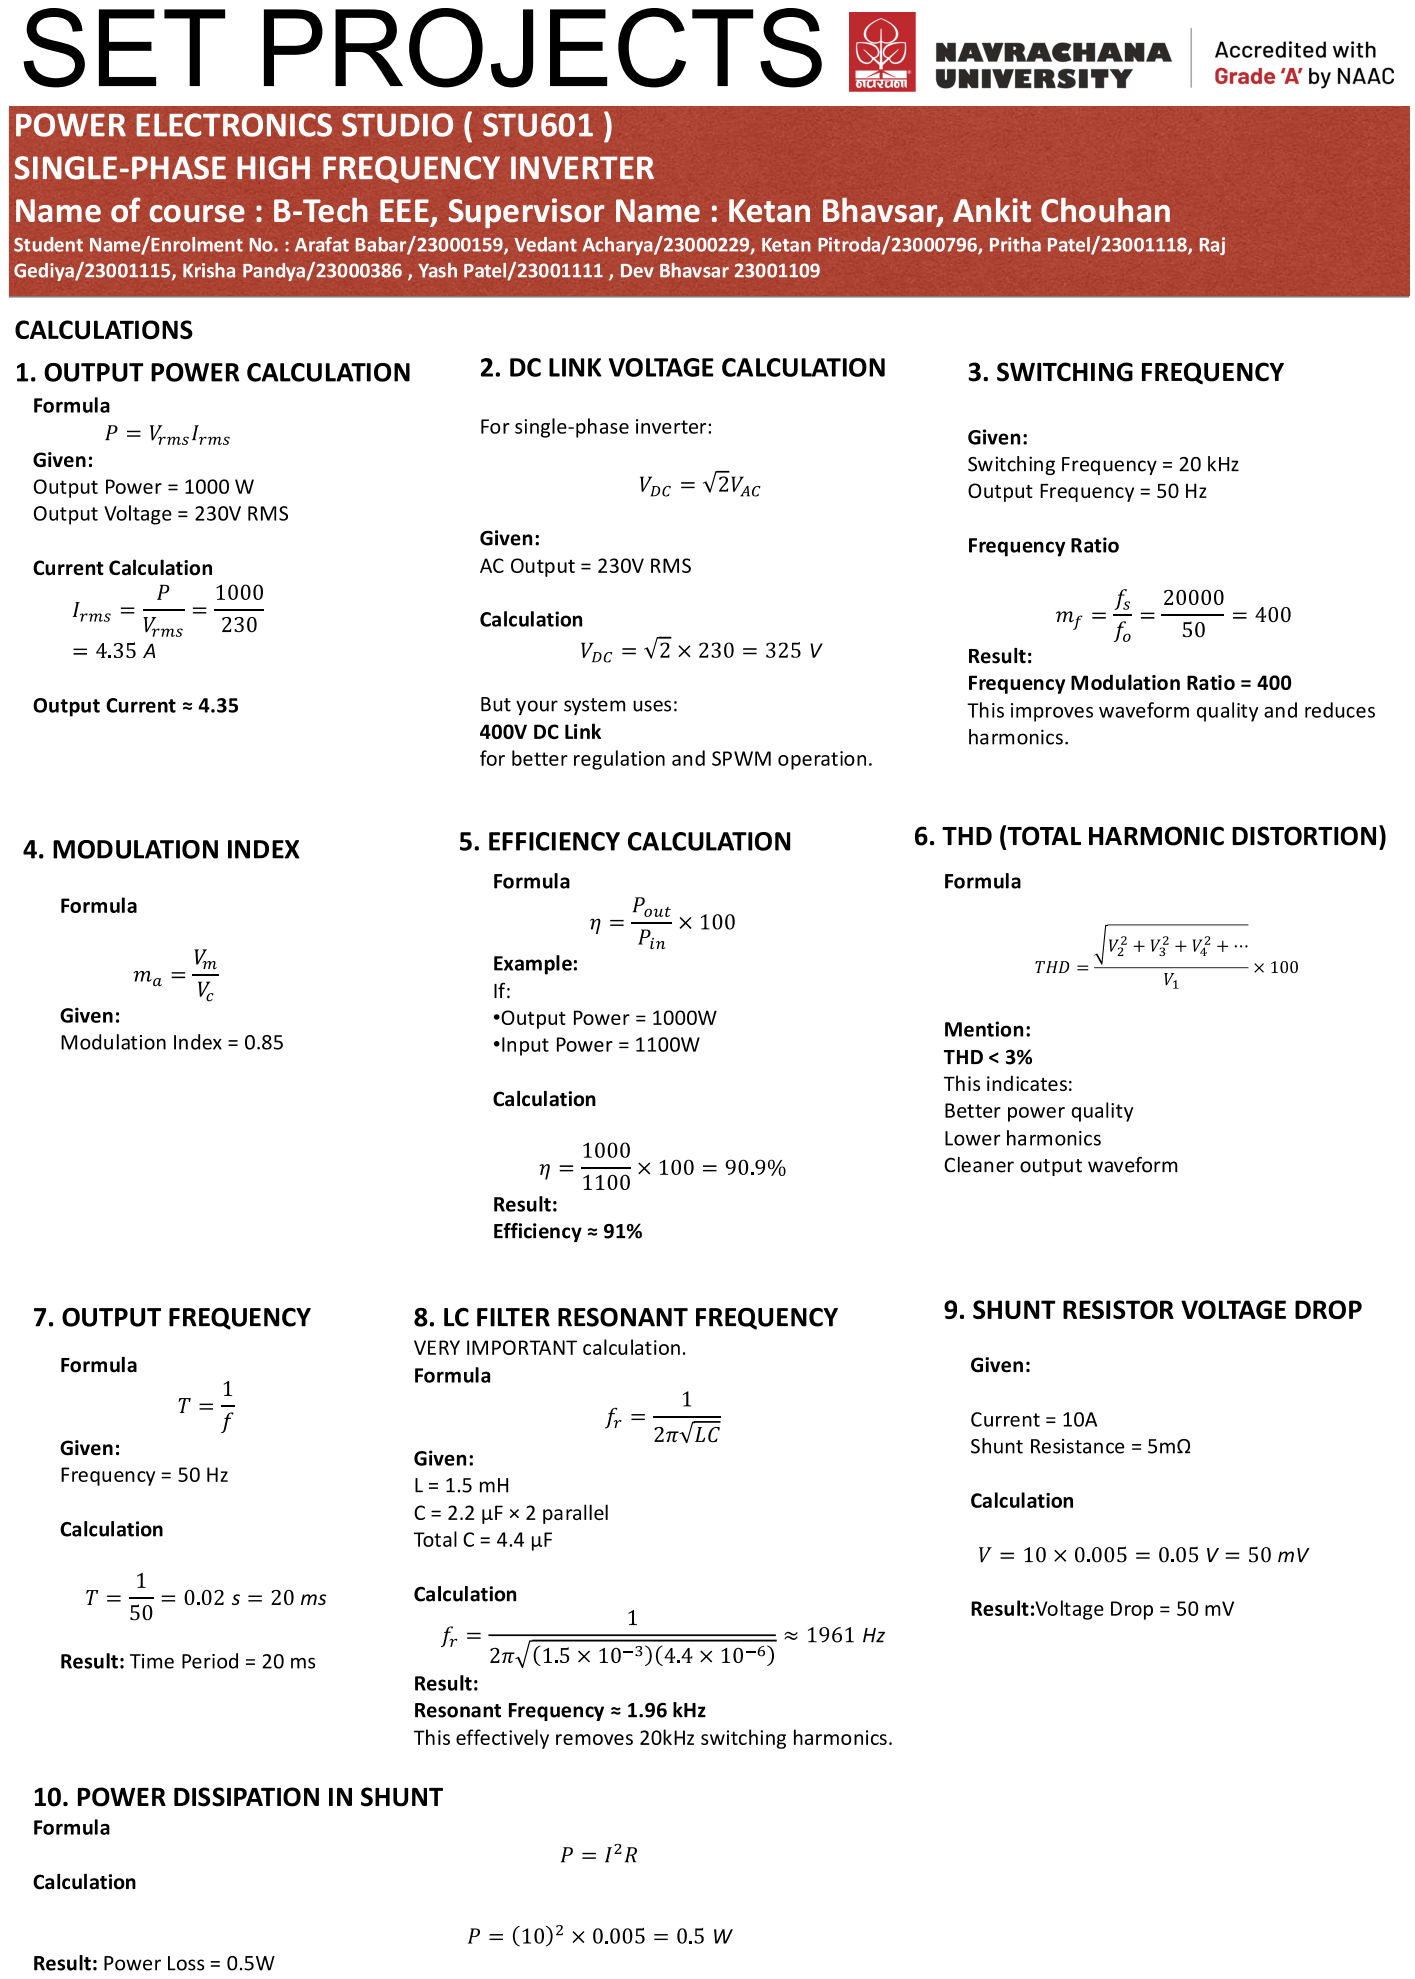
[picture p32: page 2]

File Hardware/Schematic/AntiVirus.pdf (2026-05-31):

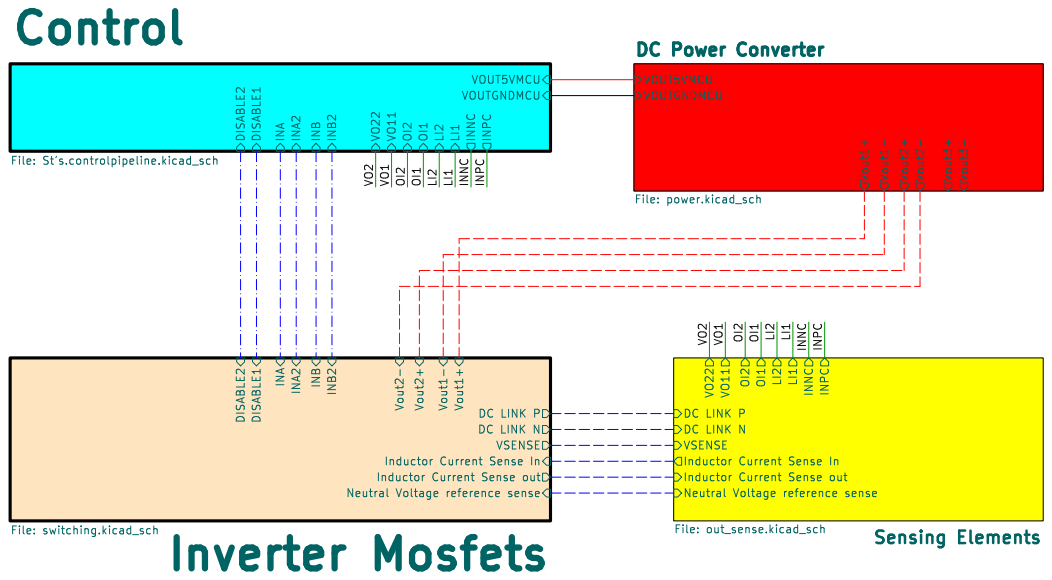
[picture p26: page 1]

DC LINK P INA INA2 INB INB2

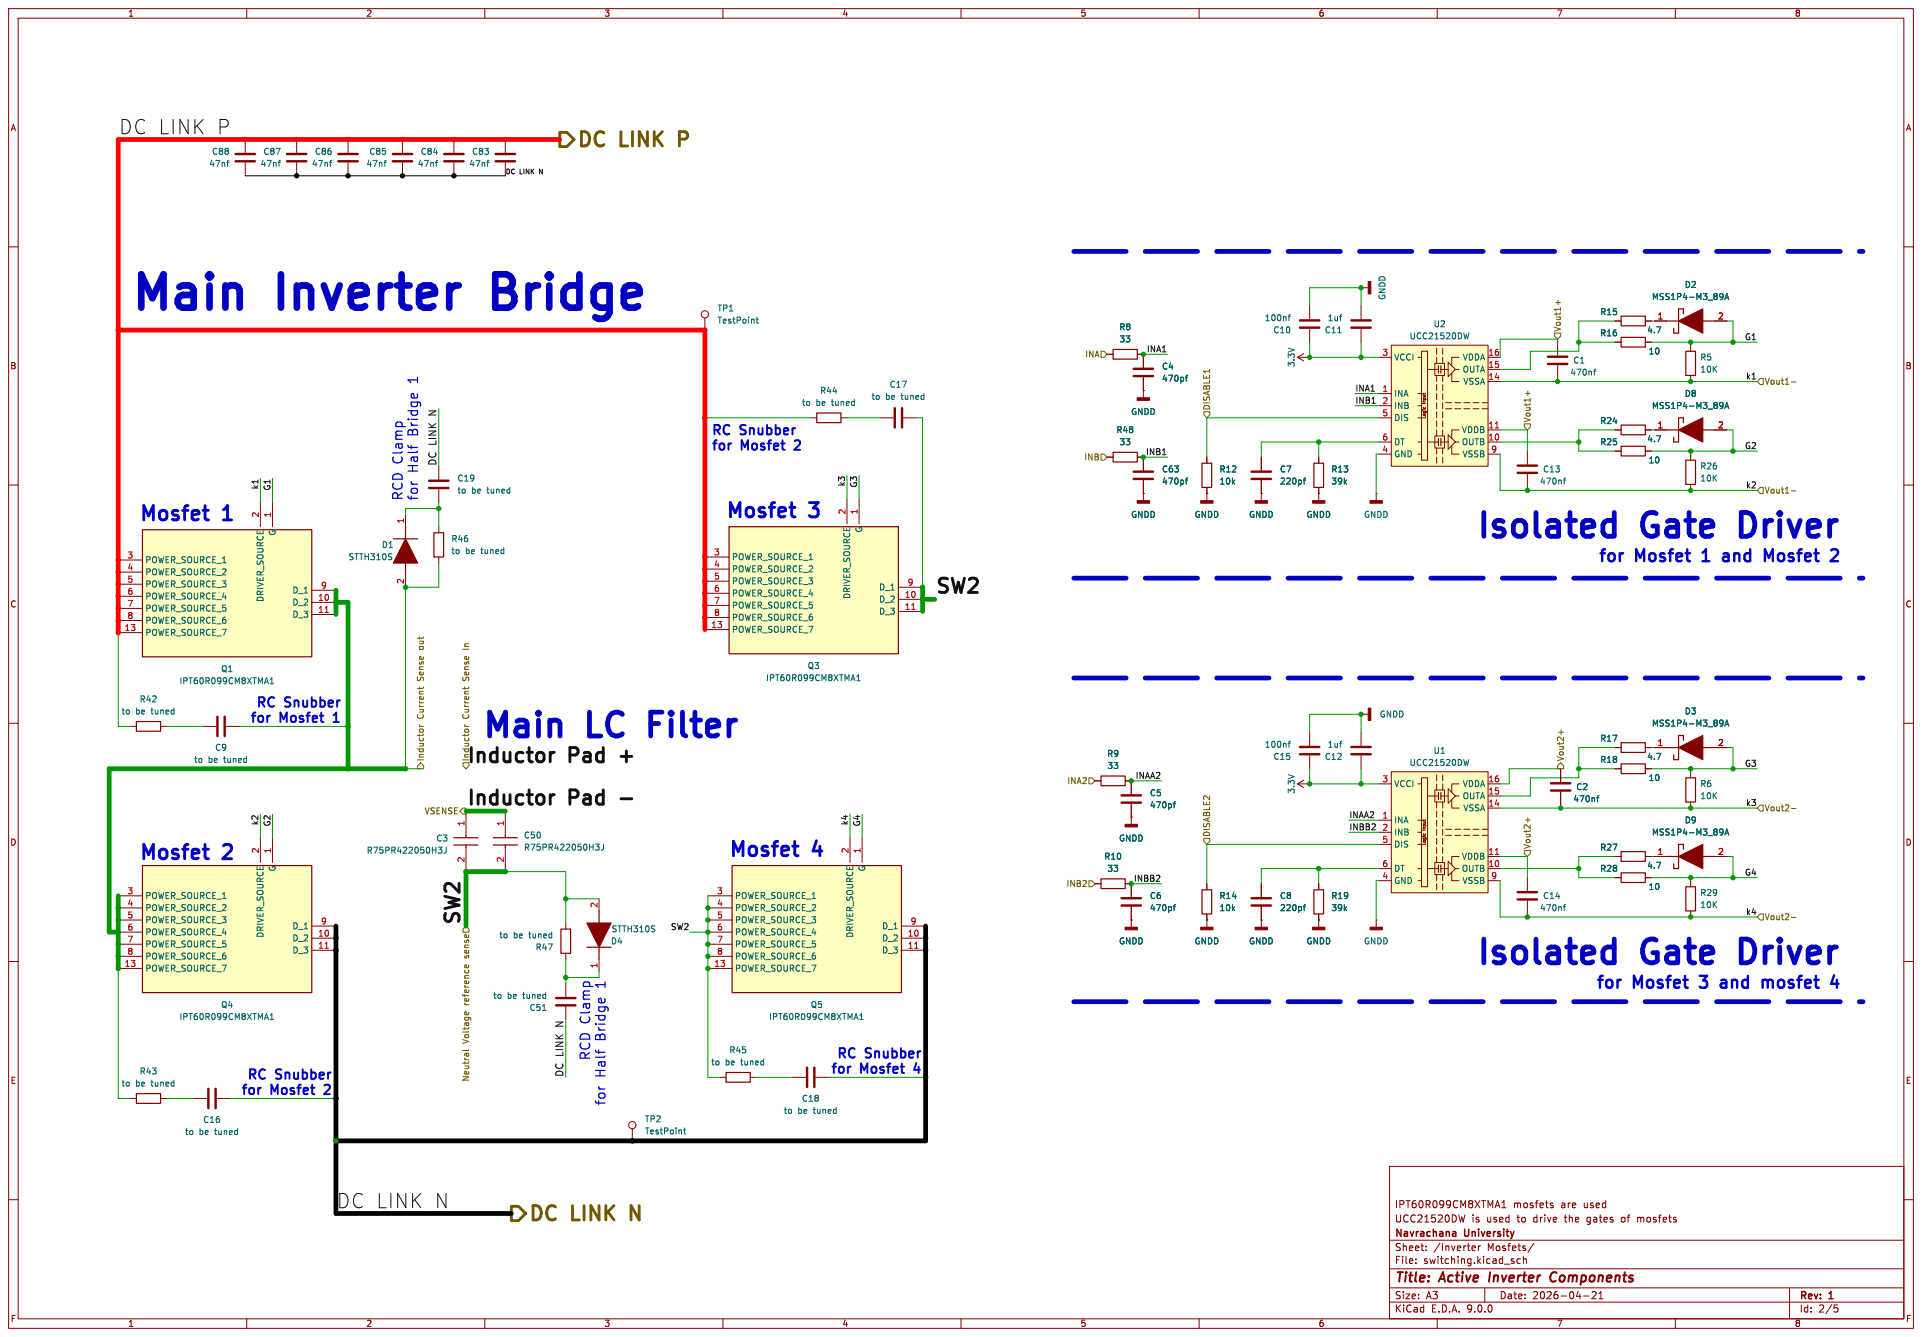
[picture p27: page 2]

for Mosfet 4 RCD Clamp for Half Bridge 1 Mosfet 2

for Mosfet 2 RCD Clamp for Half Bridge 1 Mosfet 1

for Mosfet 1 and Mosfet 2

INB2 Inductor Current Sense In

for Mosfet 3 and mosfet 4

to be tuned TP2 TestPoint

Id: 2/5 Title: Active Inverter Components

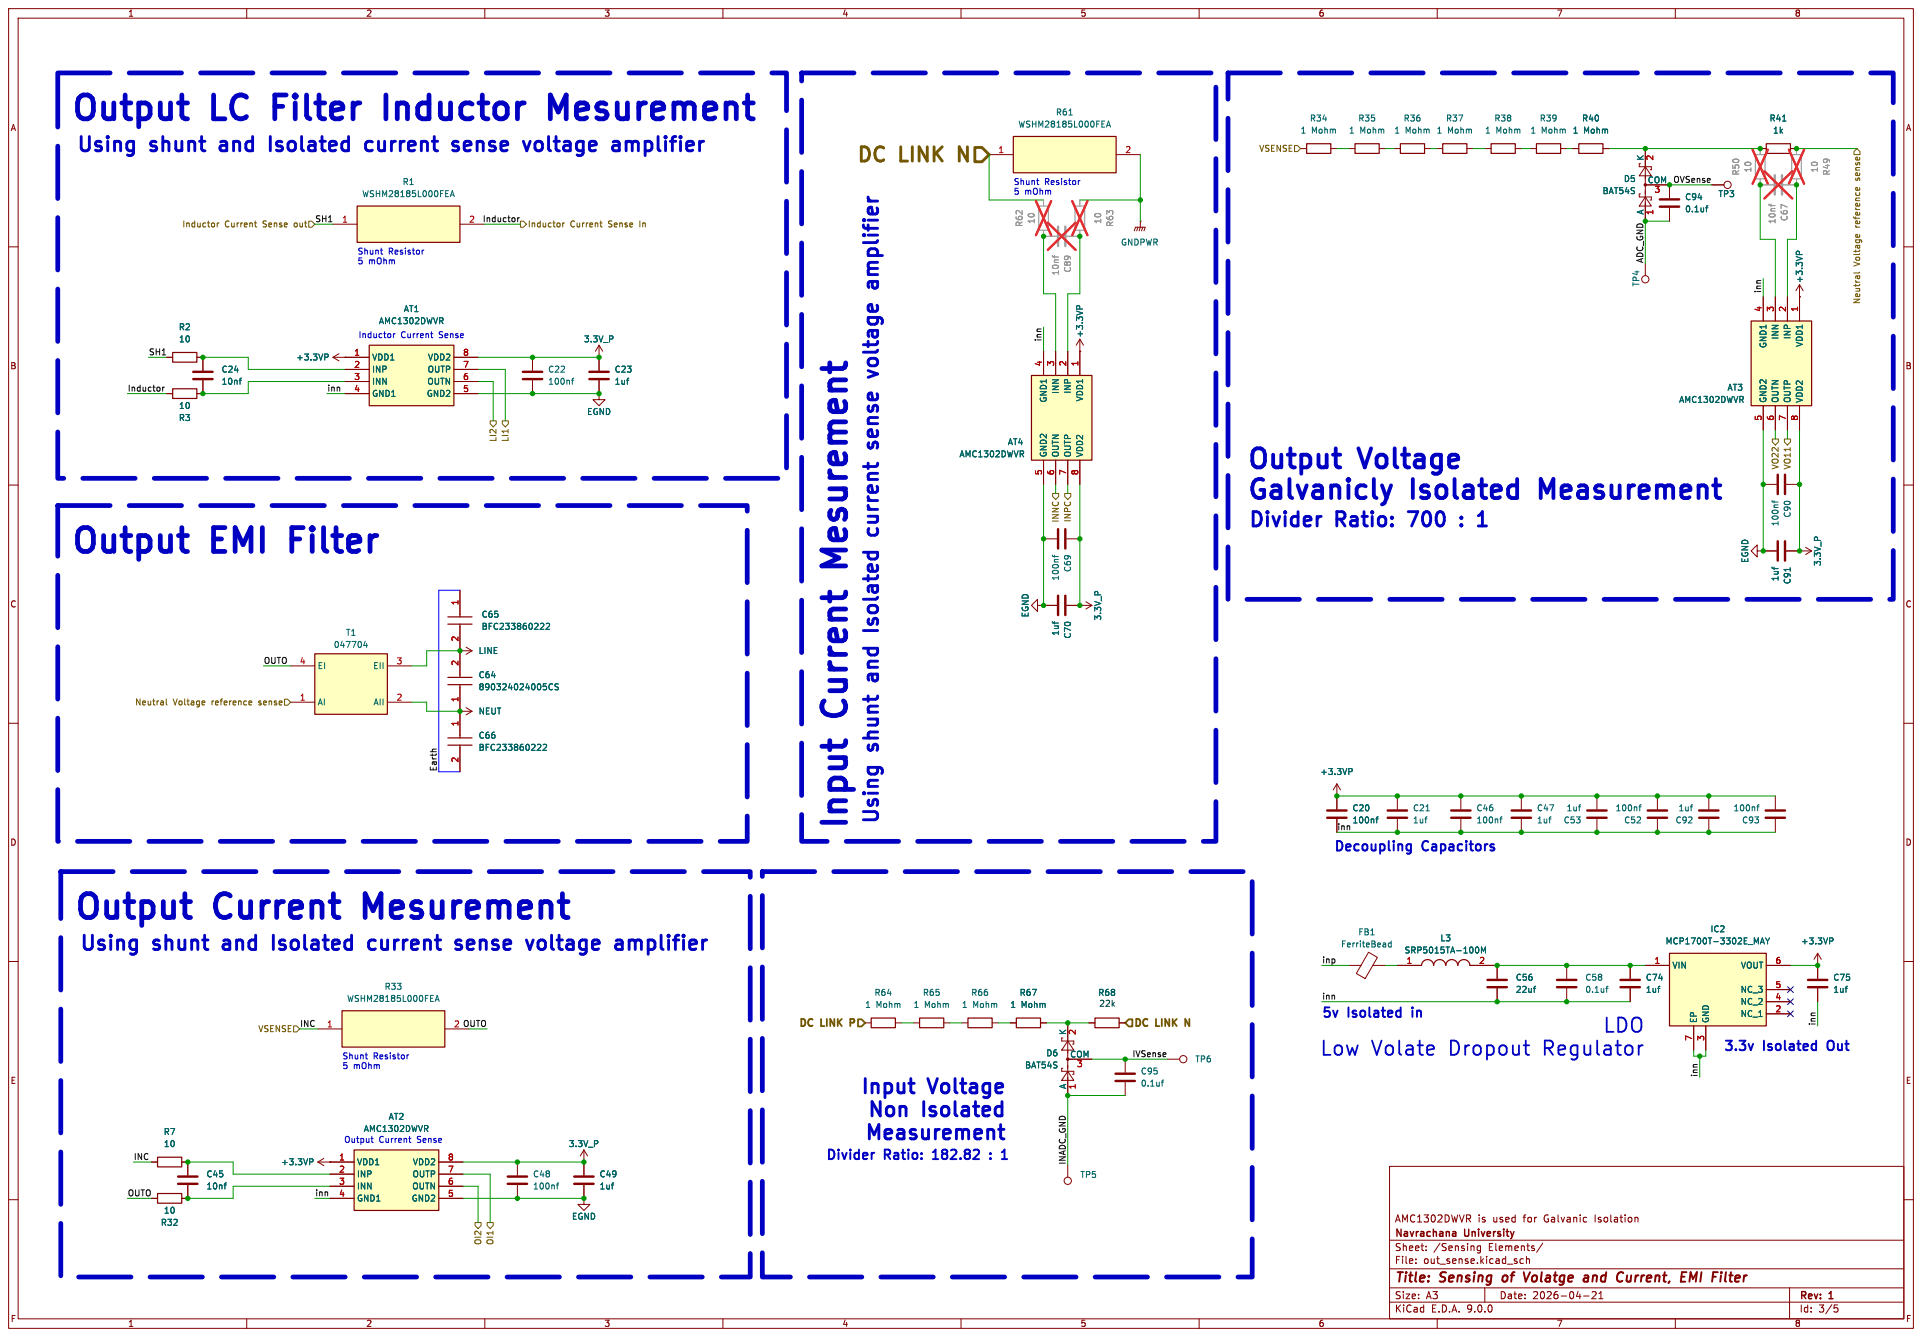
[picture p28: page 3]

Output LC Filter Inductor Mesurement
Using shunt and Isolated current sense voltage amplifier

Shunt Resistor 5 mOhm Using shunt and Isolated current sense voltage amplifier

Output Current Mesurement

inn
5v Isolated in
Low Volate Dropout Regulator

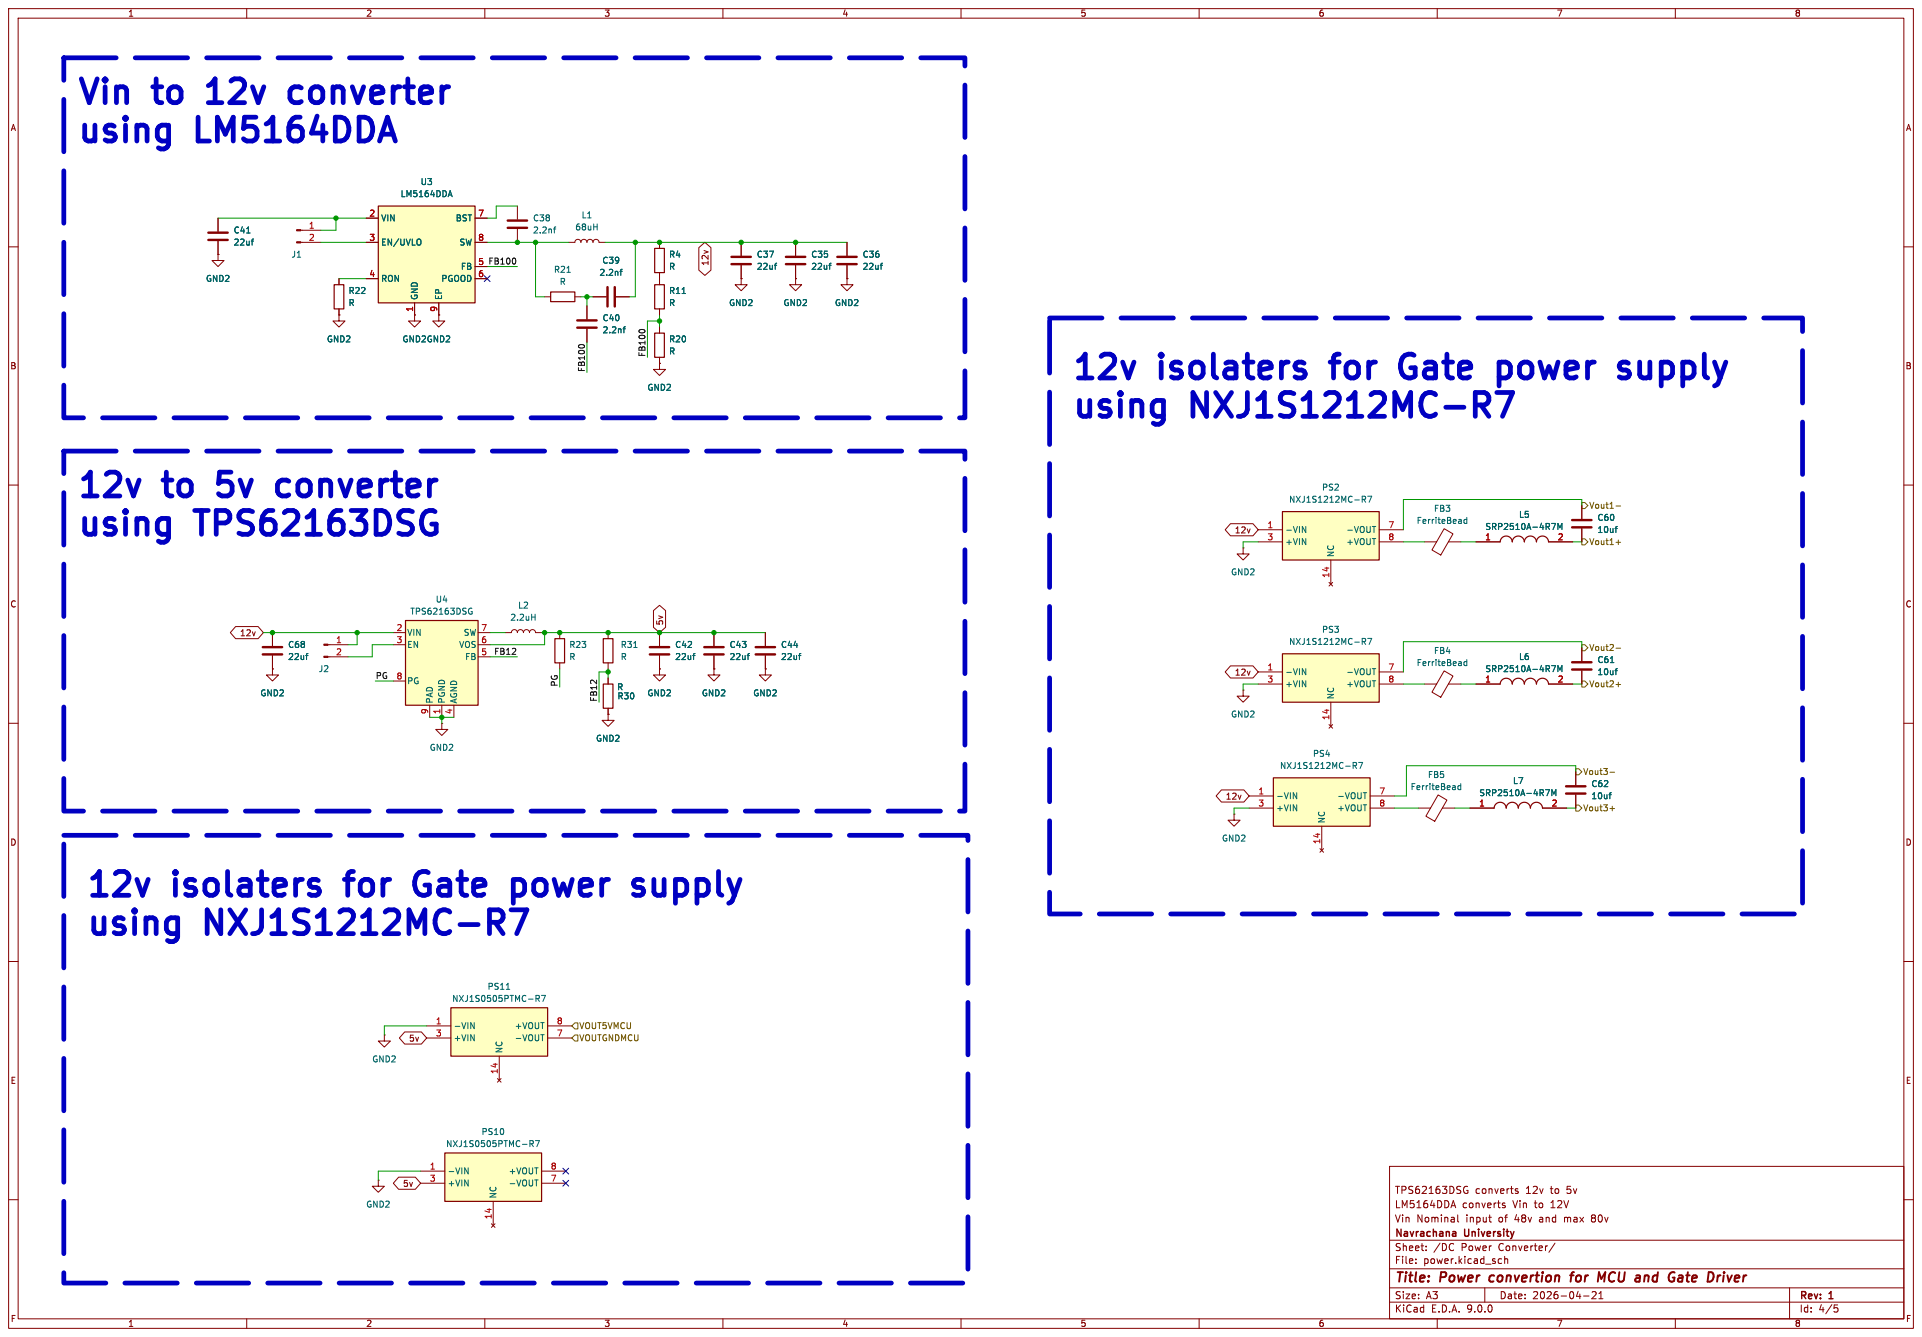
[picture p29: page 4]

9 BST 7 SW 8 FB 5 PGOOD 6 U3

12v isolaters for Gate power supply
using NXJ1S1212MC-R7

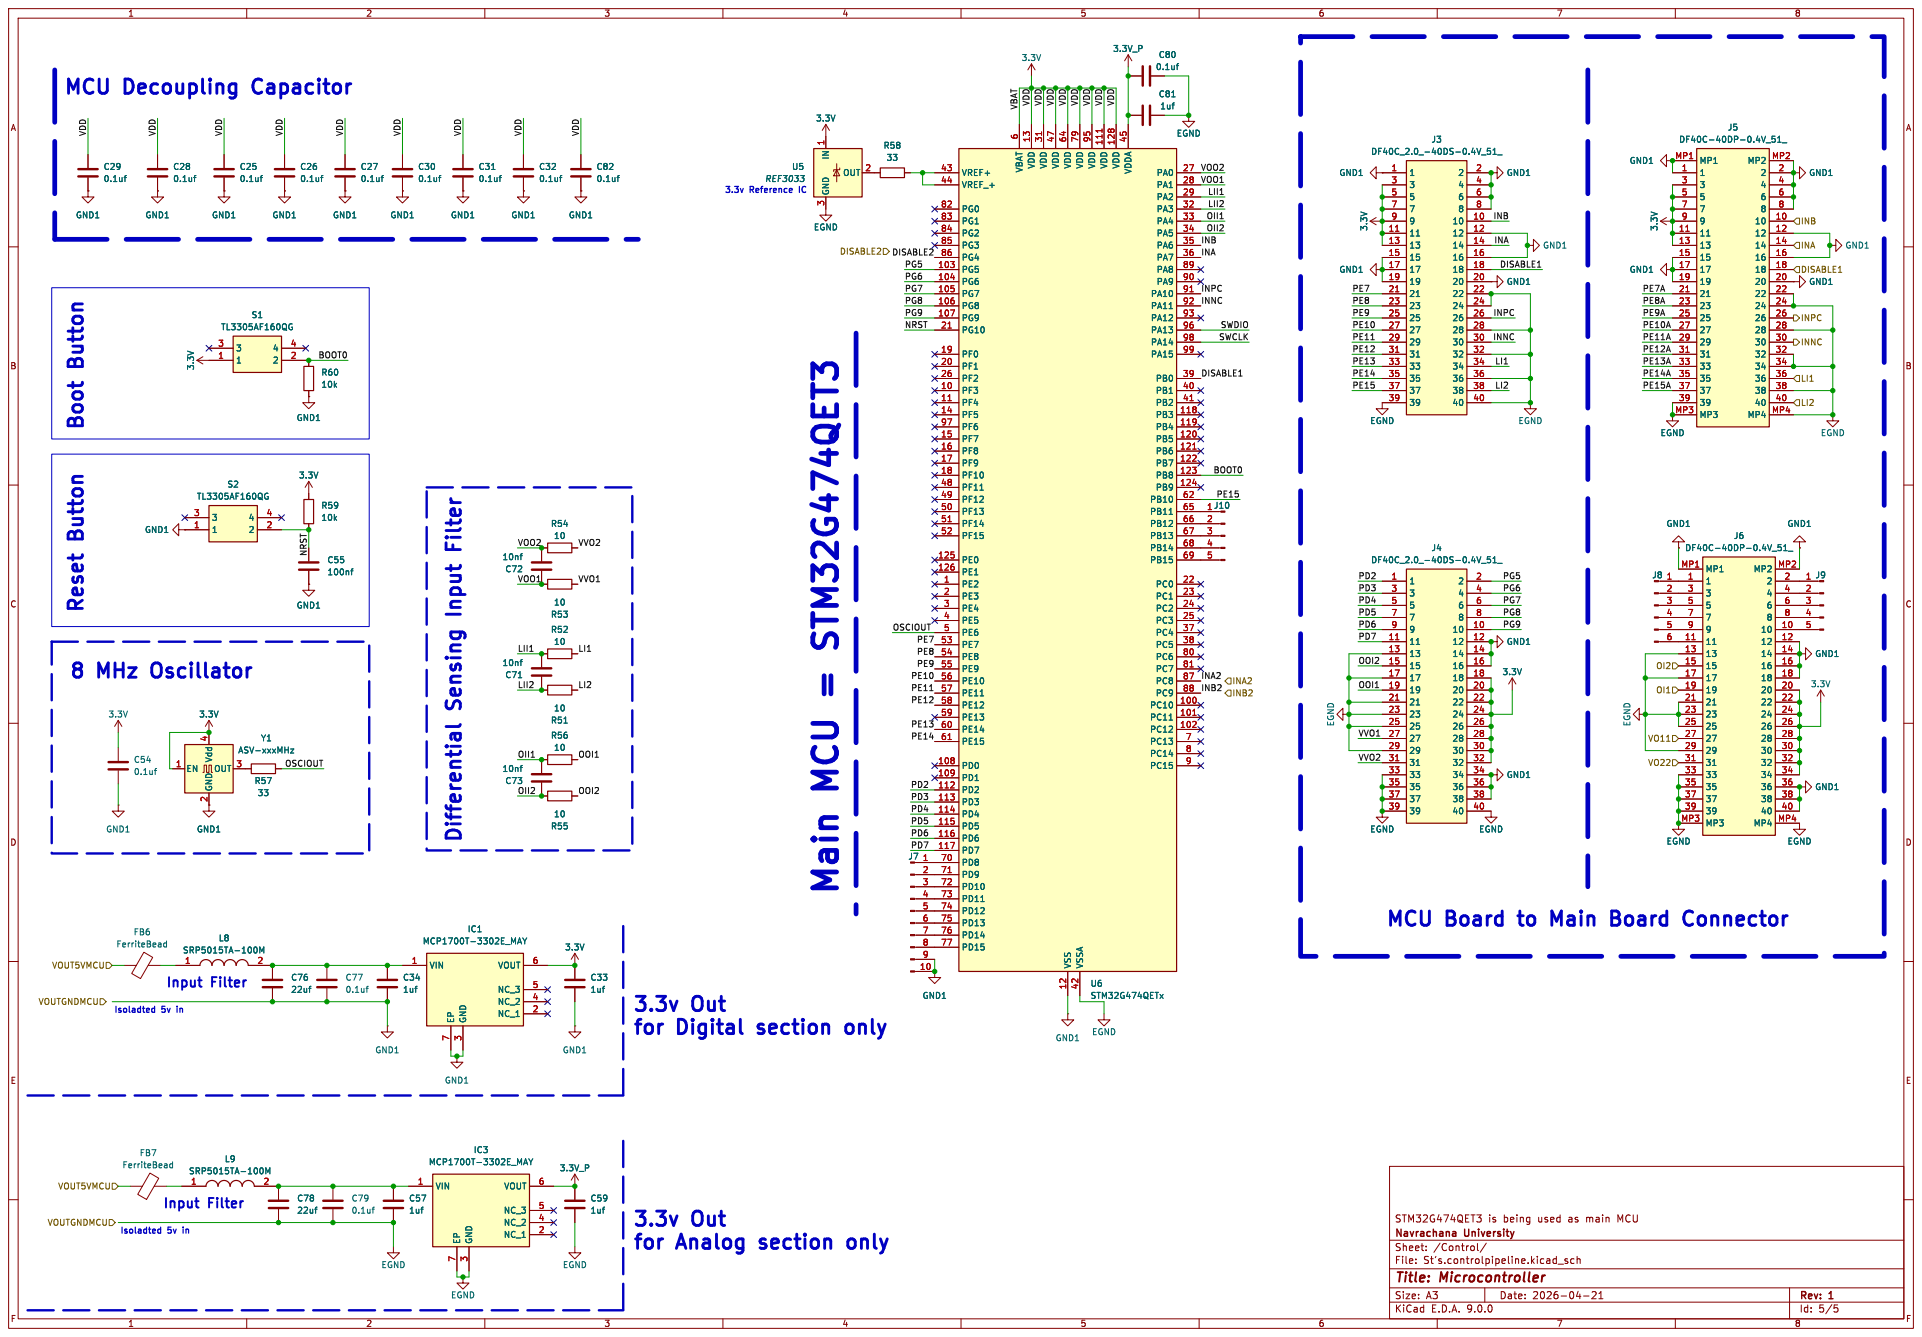
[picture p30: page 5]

3.3v Reference IC MCU Decoupling Capacitor

6 VDD 13 VDD 31 VDD 47 VDD 64 VSS 12 VDD 79 VSSA 42 VDD 95 VDD 111 VDD 128 VDDA 45 PA0 27 PA1 28 PA2 29 PA3 32 PA4 33 PA5 34 PA6 35 PA7 36 PA8 89 PA9 90 PA10 91 PA11 92 PA12 93 PA13 96 PA14 98 PA15 99 PB0 39 PB1 40 PB2 41 PB3 118 PB4 119 PB5 120 PB6 121 PB7 122 PB8 123 PB9 124 PB10 62 PB11 65 PB12 66 PB13 67 PB14 68 PB15 69 PC0 22 PC1 23 PC2 24 PC3 25 PC4 37 PC5 38 PC6 80 PC7 81 PC8 87 PC9 88 PC10 100 PC11 101 PC12 102 PC13 7 PC14 8 PC15 9 U6STM32G474QETx 1

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

0.1uf GND1 C27
8 MHz Oscillator Boot Button

MCU Board to Main Board Connector

Id: 5/5 Title: Microcontroller File: St's.controlpipeline.kicad_sch Sheet: /Control/ Navrachana University
